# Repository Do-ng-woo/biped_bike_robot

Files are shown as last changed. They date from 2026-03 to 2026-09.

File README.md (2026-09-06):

# 🤖 Biped Bike Robot

> **biped_bike_robot_print_ver6** — SolidWorks에서 설계하고 실물 구동으로 검증 중인 **이족보행 ↔ 2구동 휠 + 볼캐스터 변환 로봇**  
> ROS 2 Jazzy + Gazebo Harmonic 환경

### ✨ 현재 URDF 반영 상태
- **최신 URDF**: `urdf/biped_bike_robot.urdf`
- **원본 익스포트**: `solidworks_export/urdf/biped_bike_robot_print_ver6.urdf`
- **구조**: 20 links, 19 joints = 17 actuated revolute joints + 2 continuous knee wheel joints
- **총 질량**: 약 **1.917 kg** (`base_link`에 메인 프레임, 배터리, 제어보드 질량 반영)
- **구동 모드**: 12자유도 이족보행, 팔 지지 기반 변신, 2륜 주행 모드

---

## 🎥 실물 구동 데모

### 1. 이족 보행 (Bipedal Walking)
Bipedal Walking Demo

### 2. 차륜형 변신 (Transform to Wheeled Mode)
Transform to Wheeled Mode

### 3. 이족 보행 모드 복귀 (Reverse Transform)
Reverse Transform

### 4. 바이크 모드 주행 (Wheeled Driving)
Wheeled Driving Demo

---

## 🎬 시뮬레이션 데모

### 1. 시뮬레이션 보행
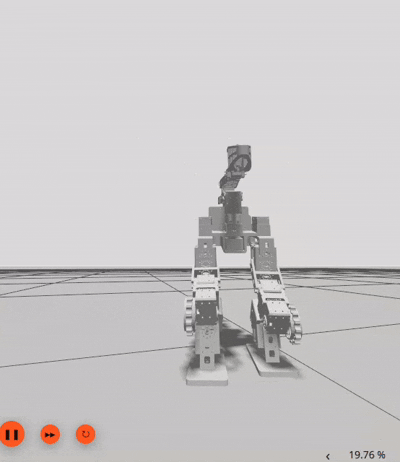
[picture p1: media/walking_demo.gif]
Simulation Walking Demo


### 2. 시뮬레이션 변신
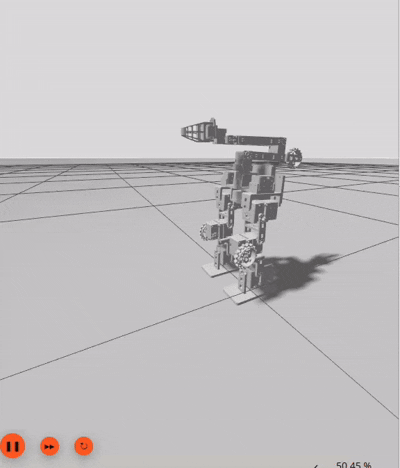
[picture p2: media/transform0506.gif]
Simulation Transform Demo


### 3. 시뮬레이션 역변신
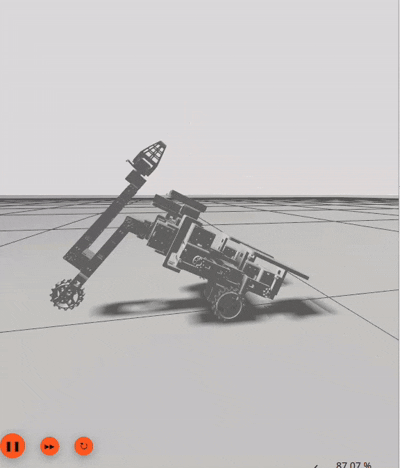
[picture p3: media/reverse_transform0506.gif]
Simulation Reverse Transform Demo


---

## 📐 관절 트리 다이어그램 (Joint Tree)

```
base_link (골반/허리 프레임)
├── [L] l_hip_yaw ──────── l_hip_yaw (좌측 고관절 요)
│   └── l_hip_roll ─────── l_hip_roll (좌측 고관절 롤)
│       └── l_hip_pitch ── l_hip_pitch (좌측 고관절 피치)
│           └── l_knee_pitch ── l_knee_pitch (좌측 무릎)
│               ├── l_ankle_pitch ── l_ankle_pitch (좌측 발목)
│               │   └── l_foot_roll ── l_foot_roll (좌측 발)
│               └── l_knee_pitch_wheel ── l_knee_pitch_wheel (좌측 무릎 휠) 🔄
│
├── [R] r_hip_yaw ──────── r_hip_yaw (우측 고관절 요)
│   └── r_hip_roll ─────── r_hip_roll (우측 고관절 롤)
│       └── r_hip_pitch ── r_hip_pitch (우측 고관절 피치)
│           └── r_knee_pitch ── r_knee_pitch (우측 무릎)
│               ├── r_ankle_pitch ── r_ankle_pitch (우측 발목)
│               │   └── r_foot_roll ── r_foot_roll (우측 발)
│               └── r_knee_pitch_wheel ── r_knee_pitch_wheel (우측 무릎 휠) 🔄
│
└── [U] arm_base_yaw ──── arm_base_yaw (팔 베이스 요)
    └── arm_shoulder_pitch ── arm_shoulder_pitch (어깨 피치)
        ├── arm_elbow_pitch ── arm_elbow_pitch (팔꿈치 피치)
        │   └── arm_wrist_pitch ── arm_wrist_pitch (손목 피치)
        │       └── arm_wrist_roll ── arm_wrist_roll (손목 롤)
```

> 🔄 = `continuous` 타입 (무한 회전 가능한 패시브 휠 관절)
> 현재 구조에서는 팔 끝 지지를 회전 휠 조인트가 아니라 볼캐스터 구조로 처리합니다.

---

## 📊 링크 목록 (20개)

| # | 링크 이름 | 위치 | 질량 (kg) | 설명 |
|---|---|---|---|---|
| 1 | `base_link` | 중심 | 0.626 | 골반/메인 프레임 (메인 기판 및 배터리 반영) |
| 2 | `l_hip_yaw` | 좌측 | 0.027 | 좌측 고관절 요 회전부 |
| 3 | `l_hip_roll` | 좌측 | 0.118 | 좌측 고관절 롤 링크 |
| 4 | `l_hip_pitch` | 좌측 | 0.014 | 좌측 고관절 피치 링크 |
| 5 | `l_knee_pitch` | 좌측 | 0.146 | 좌측 허벅지 (상부 다리) |
| 6 | `l_ankle_pitch` | 좌측 | 0.118 | 좌측 정강이 (하부 다리) |
| 7 | `l_foot_roll` | 좌측 | 0.075 | 좌측 발 |
| 8 | `l_knee_pitch_wheel` | 좌측 | 0.017 | 좌측 무릎 구동 휠 |
| 9 | `r_hip_yaw` | 우측 | 0.027 | 우측 고관절 요 회전부 |
| 10 | `r_hip_roll` | 우측 | 0.118 | 우측 고관절 롤 링크 |
| 11 | `r_hip_pitch` | 우측 | 0.014 | 우측 고관절 피치 링크 |
| 12 | `r_knee_pitch` | 우측 | 0.146 | 우측 허벅지 (상부 다리) |
| 13 | `r_ankle_pitch` | 우측 | 0.118 | 우측 정강이 (하부 다리) |
| 14 | `r_foot_roll` | 우측 | 0.075 | 우측 발 |
| 15 | `r_knee_pitch_wheel` | 우측 | 0.017 | 우측 무릎 구동 휠 |
| 16 | `arm_base_yaw` | 상체 | 0.053 | 팔 베이스 요 회전부 |
| 17 | `arm_shoulder_pitch` | 상체 | 0.105 | 상완 (어깨 피치) |
| 18 | `arm_elbow_pitch` | 상체 | 0.044 | 전완 (팔꿈치 피치) |
| 19 | `arm_wrist_pitch` | 상체 | 0.020 | 손목 피치 |
| 20 | `arm_wrist_roll` | 상체 | 0.039 | 손목 롤 / 엔드이펙터 |
> **총 질량**: 약 **1.917 kg** (URDF inertial mass 합산)

---

## 🔩 관절 목록 (19개)

### 좌측 다리 (Left Leg) — 6 액추에이터 + 1 패시브

| # | 관절 이름 | 타입 | 축 | 부모 → 자식 |
|---|---|---|-----|---|
| 1 | `l_hip_yaw` | revolute | Z(-) | base_link → l_hip_yaw |
| 2 | `l_hip_roll` | revolute | Z(-) | l_hip_yaw → l_hip_roll |
| 3 | `l_hip_pitch` | revolute | Z(+) | l_hip_roll → l_hip_pitch |
| 4 | `l_knee_pitch` | revolute | Z(-) | l_hip_pitch → l_knee_pitch |
| 5 | `l_ankle_pitch` | revolute | Z(-) | l_knee_pitch → l_ankle_pitch |
| 6 | `l_foot_roll` | revolute | Z(-) | l_ankle_pitch → l_foot_roll |
| 7 | `l_knee_pitch_wheel` | **continuous** | Z(-) | l_knee_pitch → l_knee_pitch_wheel |

### 우측 다리 (Right Leg) — 6 액추에이터 + 1 패시브

| # | 관절 이름 | 타입 | 축 | 부모 → 자식 |
|---|---|---|-----|---|
| 8 | `r_hip_yaw` | revolute | Z(-) | base_link → r_hip_yaw |
| 9 | `r_hip_roll` | revolute | Z(-) | r_hip_yaw → r_hip_roll |
| 10 | `r_hip_pitch` | revolute | Z(-) | r_hip_roll → r_hip_pitch |
| 11 | `r_knee_pitch` | revolute | Z(-) | r_hip_pitch → r_knee_pitch |
| 12 | `r_ankle_pitch` | revolute | Z(-) | r_knee_pitch → r_ankle_pitch |
| 13 | `r_foot_roll` | revolute | Z(-) | r_ankle_pitch → r_foot_roll |
| 14 | `r_knee_pitch_wheel` | **continuous** | Z(+) | r_knee_pitch → r_knee_pitch_wheel |

### 상체 (Upper Body) — 5 액추에이터

| # | 관절 이름 | 타입 | 축 | 부모 → 자식 |
|---|---|---|-----|---|
| 15 | `arm_base_yaw` | revolute | Z(-) | base_link → arm_base_yaw |
| 16 | `arm_shoulder_pitch` | revolute | Z(+) | arm_base_yaw → arm_shoulder_pitch |
| 17 | `arm_elbow_pitch` | revolute | Z(+) | arm_shoulder_pitch → arm_elbow_pitch |
| 18 | `arm_wrist_pitch` | revolute | Z(-) | arm_elbow_pitch → arm_wrist_pitch |
| 19 | `arm_wrist_roll` | revolute | Z(-) | arm_wrist_pitch → arm_wrist_roll |

---

## 🦿 설계 특징

### 1. 좌우 대칭 이족 구조
- 각 다리: **6 DOF** (Hip Yaw → Hip Roll → Hip Pitch → Knee Pitch → Ankle Pitch → Foot Roll)
- 좌우 다리는 `base_link`에서 Y축 방향으로 오프셋 (좌: y=-0.01425, 우: y=-0.13925)
- 고관절 롤(Roll)은 `rpy="0 -π/2 0"`로 90° 회전하여 측면 운동축을 구현

### 2. 차륜 모드를 위한 휠과 볼캐스터
- `l_knee_pitch_wheel_jnt`, `r_knee_pitch_wheel_jnt` — 2개의 **continuous** 구동 휠 관절
- 팔 끝 지지는 `arm_wheel_pitch_` 조인트 없이 볼캐스터 구조로 처리

### 3. 단일 팔 지지 구조
- `arm_base_yaw` → `arm_shoulder_pitch` → `arm_elbow_pitch` → `arm_wrist_pitch` → `arm_wrist_roll`
- `arm_wrist_roll`이 자전거 핸들을 잡는 최종 엔드이펙터

### 4. 서보 모터 기반 소형 로봇
- 총 질량 약 **1.917 kg**
- 모든 메시가 STL 형식 (SolidWorks 직접 내보내기)
- URDF에는 Gazebo friction/contact 및 `ros2_control` 인터페이스가 포함되어 있습니다.

---

## 📁 패키지 구조

```
biped_bike_robot/
├── CMakeLists.txt
├── package.xml
├── RL_walking/                 ← 독립형 NumPy RL 보행 + OpenCR 브리지
├── manipulator/                ← 리더/팔로워/카메라/지도학습 웹 스택
├── README.md                    ← 이 문서
├── config/
│   ├── controllers.yaml         ← ros2_control 컨트롤러 설정
│   └── dynamixel_hardware.yaml  ← 실물 Dynamixel ID/방향/제한 설정
├── launch/
│   ├── display.launch.py        ← RViz 모델 표시
│   ├── gazebo.launch.py         ← Gazebo 시뮬레이션 런치
│   └── hardware_display.launch.py ← 실물 브릿지 + RViz/robot_state_publisher
├── media/
│   ├── walking.gif              ← 실물 보행 데모
│   ├── transform.gif            ← 실물 변신 데모
│   ├── revert_transform.gif     ← 실물 역변신 데모
│   ├── drive.gif                ← 실물 주행 데모
│   ├── walking_demo.gif         ← 시뮬레이션 보행 데모
│   ├── transform0506.gif        ← 시뮬레이션 변신 데모
│   └── reverse_transform0506.gif ← 시뮬레이션 역변신 데모
├── meshes/                      ← 메시 파일 (20개 STL)
│   ├── base_link.STL
│   ├── l_hip_yaw.STL
│   ├── l_hip_roll.STL
│   ├── l_hip_pitch.STL
│   ├── l_knee_pitch.STL
│   ├── l_ankle_pitch.STL
│   ├── l_foot_roll.STL
│   ├── l_knee_pitch_wheel.STL
│   ├── r_hip_yaw.STL
│   ├── r_hip_roll.STL
│   ├── r_hip_pitch.STL
│   ├── r_knee_pitch.STL
│   ├── r_ankle_pitch.STL
│   ├── r_foot_roll.STL
│   ├── r_knee_pitch_wheel.STL
│   ├── arm_base_yaw.STL
│   ├── arm_shoulder_pitch.STL
│   ├── arm_elbow_pitch.STL
│   ├── arm_wrist_pitch.STL
│   └── arm_wrist_roll.STL
├── urdf/
│   └── biped_bike_robot.urdf    ← 최신 보정 URDF (print ver6 기반)
├── scripts/
│   ├── ik_walker.py             ← IK 기반 보행 엔진
│   ├── transform_bike.py        ← 바이크 모드 변신 시퀀스
│   ├── revert_bike.py           ← 이족보행 모드 복구 시퀀스
│   ├── bike_teleop.py           ← 키보드(WASD) 주행 컨트롤러
│   ├── dxl_joint_state_bridge.py ← 실물 Dynamixel 브릿지
│   ├── imu_base_tf.py           ← 실물 자세 TF 보정
│   ├── web_control.py           ← 실물 테스트용 웹 컨트롤 패널
│   ├── ready_posture.py         ← 기본 준비 자세 초기화
│   └── patch_urdf.py            ← SolidWorks→ROS 2 자동 보정 도구
└── solidworks_export/             ← SolidWorks 원본 (수정 금지)
    ├── README.md
    ├── urdf/biped_bike_robot_print_ver6.urdf
    └── meshes/
```

## 🌐 통합 웹 제어

ROS 2 Jazzy 환경에서 소스 패키지의 통합 웹 패널을 실행합니다.

```bash
python3 scripts/web_control.py
```

다른 PC에서는 `http://로봇_IP:8080`으로 접속합니다. 첫 화면의 **RL
Walking**은 패키지 내부 `RL_walking/models/model_90000.npz`를 사용하며,
W/↑ 전진, A/←·D/→ 횡이동, Q/E 회전, Space 정지로 동작합니다. 키를
놓으면 dead-man 타임아웃으로 정지 명령이 전송됩니다.

상단 **Manipulator** 링크는 별도 페이지를 열고, OpenCR 하체/팔로워,
OpenRB 리더, USB 카메라와 매니퓰레이터 UI를 한 번에 시작합니다.
RL 보행, 기존 하드웨어 브리지, 매니퓰레이터 스택은 같은 OpenCR 포트를
사용하므로 웹 서버가 세 모드의 동시 실행을 차단합니다.

---

## 🔗 관절 연쇄 다이어그램 (Kinematic Chain)

```mermaid
graph TD
    B["base_link<br/>골반 프레임<br/>626g"]

    B -->|l_hip_yaw| LHY["l_hip_yaw<br/>27g"]
    LHY -->|l_hip_roll| LHR["l_hip_roll<br/>118g"]
    LHR -->|l_hip_pitch| LHP["l_hip_pitch<br/>14g"]
    LHP -->|l_knee_pitch| LK["l_knee_pitch<br/>146g"]
    LK -->|l_ankle_pitch| LA["l_ankle_pitch<br/>118g"]
    LA -->|l_foot_roll| LF["l_foot_roll<br/>75g"]
    LK -.->|wheel| LKW["l_knee_pitch_wheel 🔄<br/>17g"]

    B -->|r_hip_yaw| RHY["r_hip_yaw<br/>27g"]
    RHY -->|r_hip_roll| RHR["r_hip_roll<br/>118g"]
    RHR -->|r_hip_pitch| RHP["r_hip_pitch<br/>14g"]
    RHP -->|r_knee_pitch| RK["r_knee_pitch<br/>146g"]
    RK -->|r_ankle_pitch| RA["r_ankle_pitch<br/>118g"]
    RA -->|r_foot_roll| RF["r_foot_roll<br/>75g"]
    RK -.->|wheel| RKW["r_knee_pitch_wheel 🔄<br/>17g"]

    B -->|arm_base_yaw| ABY["arm_base_yaw<br/>53g"]
    ABY -->|shoulder_pitch| ASP["arm_shoulder_pitch<br/>105g"]
    ASP -->|elbow_pitch| AEP["arm_elbow_pitch<br/>44g"]
    AEP -->|wrist_pitch| AWP["arm_wrist_pitch<br/>20g"]
    AWP -->|wrist_roll| AWR["arm_wrist_roll<br/>39g"]

    style B fill:#4a90d9,color:#fff
    style LF fill:#2ecc71,color:#fff
    style RF fill:#2ecc71,color:#fff
    style AWR fill:#e74c3c,color:#fff
    style LKW fill:#f39c12,color:#fff
    style RKW fill:#f39c12,color:#fff
```

---

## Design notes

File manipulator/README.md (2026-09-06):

# Biped Bike Manipulator (native ROS 2)

이 폴더는 Docker 없이 ROS 2 Jazzy 호스트에서 다음 기능을 한 번에 실행한다.

- 기존 12축 하체를 변신 시퀀스의 `DEEP_SQUAT_ARMS_UP` 하체 각도로 이동하고 지속 고정
- OpenRB에 연결된 OMX-L 리더 6축(ID 21~26)을 실제 팔로워 6축(ID 15~20)으로 텔레오퍼레이션
- U20CAM 영상, 실제 팔 관절각, 리더 목표각을 에피소드 단위로 기록
- 로컬 GPU에서 영상 기반 지도학습(behavior cloning)
- 학습 모델을 불러와 실제 팔에 추론 명령 전송
- 브라우저에서 상태·카메라·기록·학습·추론 제어

다른 `biped_bike_robot` 파일은 수정하지 않는다. 하체는 외부 PD 루프를 사용하지 않는다. 활성 모드에서는 하나의 command arbiter가 매 주기 하체 고정 12축과 팔/그리퍼 목표 6축을 합친 18축 trajectory를 발행하고, Dynamixel 내부 position PID가 이를 추종한다. 휠 명령은 모든 모드에서 계속 0으로 보낸다.

## 안전 및 현재 범위

팔로워의 기존 5축 뒤에 `arm_gripper_jnt`를 추가해 OpenCR ID 20과 연결한다. 리더 `gripper_joint_1`(OpenRB ID 26)의 시작 위치를 팔로워 ID 20의 시작 위치에 자동 정렬한 뒤 상대 각도를 추종한다. 실행 시 원본 하드웨어 YAML을 수정하지 않고 `data/runtime/dynamixel_hardware_with_gripper.yaml`을 생성한다. ID 20은 다른 팔 관절과 동일한 일반 Position Control Mode(Operating Mode 3)를 사용한다. Wizard에서 측정한 팔로워 기구 끝점은 닫힘 181.14도(2061 tick), 열림 108.63도(1236 tick)다. 닫힘은 기구 끝점에서 약 0.5도 여유를 둔 2055 tick, 열림은 1.22 rad 범위로 사용한다. 기록에서 열림 값이 증가하는 리더 ID 26은 `+1`, 열릴 때 tick이 감소하는 팔로워 ID 20의 하드웨어 변환은 `-1`로 두어 서로 반대인 물리 회전 방향을 맞춘다. 리더의 더 큰 gripper 회전 범위에는 0.72 배율을 적용해 팔로워 개폐율로 환산하므로 중간 영역이 양 끝값에 포화되지 않는다. ID 20 PWM limit은 다른 관절과 같은 885다.

실시간 텔레옵에서는 기존 브리지의 18개 개별 위치 읽기를 사용하지 않는다. 이 폴더의 `dxl_joint_state_bridge_streaming.py`가 원본 브리지를 읽어 확장하고, 20개 모터 상태를 ID 1~7, 8~14, 15~20의 세 GroupSyncRead로 나눠 20 Hz 수집한다. 한 하체 그룹의 패킷이 빠져도 팔과 그리퍼 피드백은 독립적으로 유지된다. 30 Hz로 들어오는 단일 목표점은 매번 보간을 재시작하지 않고 즉시 GroupSyncWrite하며 1 tick 변화부터 반영한다. Ready/Kneeling 같은 다점 궤적만 기존 시간 보간을 유지한다. 원본 `scripts/dxl_joint_state_bridge.py`는 수정하지 않는다.

처음에는 로봇을 공중에 띄우거나 비상 정지가 가능한 상태에서 낮은 속도로 확인한다. `config/system.yaml`의 `arm.direction`, `arm.offset`, 관절 한계가 실제 장착 방향과 맞는지 축별로 확인해야 한다. 기존 주행/변신 제어 프로그램과 이 프로그램을 동시에 실행하면 같은 모터 명령 토픽을 두 노드가 사용할 수 있으므로 동시에 실행하지 않는다.

## 1. 환경 준비

ROS와 기존 두 워크스페이스를 먼저 불러온다.

```bash
source /opt/ros/jazzy/setup.bash
source /home/dongwoo/install/setup.bash
source /home/dongwoo/biped_bike_ws/install/setup.bash
cd /home/dongwoo/biped_bike_ws/src/biped_bike_robot/manipulator
```

학습 환경은 최초 한 번만 설치한다. PyTorch와 OpenCV가 이 폴더의 `.venv-training`에 설치되고 호스트 ROS 패키지는 읽기 전용으로 공유되며, 다른 Python 환경을 바꾸지 않는다.

```bash
./setup_native.sh
```

장치까지 점검한다.

```bash
./validate_native.py --hardware --leader --camera --training
```

`/dev/opencr`가 없다면 기존 biped 하드웨어 설정에서 사용하는 udev 별칭을 먼저 준비한다. 카메라 번호가 달라졌다면 안정적인 `/dev/v4l/by-id/...-video-index0` 경로로 `config/system.yaml`의 `camera.device`를 바꾸는 것이 좋다.

## 2. 실행

현재 Docker 버전이 카메라나 OpenRB를 잡고 있다면 먼저 해당 컨테이너를 중지한다. 그 뒤:

```bash
./run_native.sh --hardware --leader --camera --ready-on-start
```

브라우저에서 `http://localhost:8000`을 연다. 같은 네트워크의 다른 PC에서는 `http://노트북_IP:8000`으로 접속한다.

하드웨어 없이 UI와 ROS 노드만 확인하려면:

```bash
./run_native.sh
```

`--ready-on-start`를 준 경우에만 OpenCR 브리지가 초기화된 뒤 ID 20 gripper를 포함한 완전한 18축 `/joint_states`를 먼저 기다린다. 그 실측 자세에서 기존 `scripts/bike_transform_sequence.py`의 `HARDWARE_READY`와 gripper 중립값 0 rad까지, MJLab `run_ros_bridge.py`와 같은 cubic smoothstep(`a=t²(3-2t)`) 프로파일을 50 Hz/151개 궤적점으로 만들어 3초 동안 이동한다. 따라서 3초를 기다렸다가 목표로 튀는 방식이 아니며 시작과 끝 속도도 완만하다. 브리지 자체의 즉시 startup posture는 항상 끈다. 실제 로봇을 지지하고 주변을 비운 상태에서 사용한다. 옵션을 생략하면 시작 시 자동 자세 이동은 하지 않는다. 초기 고정 모드에서는 OpenCR IMU를 사용하지 않는다.

하체는 ROS overlay에서 발견되는 오래된 설치본을 사용하지 않고 `config/system.yaml`에 지정된 현재 biped 소스의 `dxl_joint_state_bridge.py`를 직접 실행한다. 원본 `dynamixel_hardware.yaml`에 이 모듈의 ID 20 설정만 합친 런타임 YAML을 사용한다. 리더도 크래시 이력이 있는 `omx_l_leader_ai.launch.py`/`controller_manager` 대신 이 모듈의 `leader_openrb_reader.py`가 OpenRB ID 21~26의 Present Position만 읽는다. 이 리더 노드는 위치 및 토크 명령을 전송하지 않는다.

## 3. 텔레오퍼레이션

웹에서 다음 두 버튼을 순서대로 누른다.

1. **1. Kneeling Stable**: 휠 속도를 0으로 만들고 전체 18축을 기존 `DEEP_SQUAT_ARMS_UP`과 gripper 중립 자세로 4초 동안 smoothstep 이동한다. 실제 하체 관절이 목표 오차 0.12 rad 안에서 0.5초 유지돼야 상태가 `STABLE`이 된다.
2. **2. Manipulating Teleop**: `STABLE` 상태에서만 활성화된다. 리더와 팔로워의 현재 위치를 6축 모두 자동 정렬한 뒤 팔과 gripper 명령을 허용한다.

Record와 Inference도 동일하게 먼저 `STABLE` 확인이 필요하다. 안정화 전 직접 요청해도 웹 API와 ROS 상태 머신 양쪽에서 거부한다.

전환이 15초 안에 완료되지 않으면 `FAULT`가 되고 팔 명령은 차단된다. 활성화 후에도 하체 오차와 joint-state 수신을 계속 감시하며, 허용 오차가 0.3초 이상 지속되거나 상태 수신이 끊기면 `FAULT`로 전환한다. **Arm Stop / Idle**은 새 팔 명령을 끊지만 하체는 마지막 고정 목표를 유지한다.

자세 숫자는 이 폴더에 복사해 두지 않고 기존 `scripts/bike_transform_sequence.py`에서 매 실행 시 직접 읽는다.

| 관절 | Ready | Manipulation kneeling |
|---|---:|---:|
| 왼 hip pitch | 0° | -44.48° |
| 오른 hip pitch | 0° | +44.48° |
| 양 knee pitch | -17.19° | -120° |
| 양 ankle pitch | +18.59° | +85° |
| arm shoulder pitch | -70° | -70° |
| arm elbow pitch | 0° | +20° |

무릎 전환 timeout 시 웹 상태의 `lower_error_rad`와 `largest errors`에 목표에서 가장 멀리 남은 관절이 표시된다. `Skipped ... trajectory joints over their absolute command limits`가 나오면 현재 관절 zero/center 설정을 먼저 확인한다. 실행 로그의 Dynamixel config 경로는 이 모듈 아래 `manipulator/data/runtime/dynamixel_hardware_with_gripper.yaml`이어야 한다.

## 4. 데이터 기록

웹의 Dataset recording 항목을 채우고 **Start**를 누른다. UI가 먼저 고정 무릎 자세 완료를 기다린 뒤 기록을 시작한다.

- `Warmup`: 준비 시간
- `Episode sec`: 한 에피소드 기록 시간
- `Reset timeout sec`: 팔을 기존 `DEEP_SQUAT_ARMS_UP`의 팔 자세로 복귀시키는 제한 시간
- `Stop`: 현재 에피소드를 저장하고 일시 정지
- `Retry`: 현재/직전 에피소드를 버리고 다시 기록
- `Next`: 현재 에피소드를 저장하고 다음 에피소드로 이동
- `Finish`: 남은 유효 샘플을 저장하고 데이터셋 확정

에피소드 사이에는 팔로워를 설정된 reset 자세로 이동시키고 실제 관절 오차가 허용 범위에서 0.5초 유지되는지 확인한다. 그 뒤 리더 기준을 현재 팔로워 자세에 다시 정렬하고 다음 warmup을 시작한다.

데이터는 이 폴더 아래 `data/datasets/<user>/<name_timestamp>/`에만 저장한다. 각 에피소드에는 JPEG 프레임, `camera.mp4`, `samples.npz`, `episode.json`이 생긴다. `samples.npz`에는 카메라 시간, 실제 팔 관절 시간·각도(`observation_state`), 리더 목표 시간·각도(`action`)가 저장된다. 카메라를 기준으로 가장 가까운 관절/명령 샘플을 선택하고 기본 50 ms를 초과한 조합은 기록하지 않는다.

## 5. 학습과 실행

**Finish** 후 Training의 Refresh를 누르고 데이터셋을 선택한 뒤 **Start Training**을 누른다. 기본 모델은 카메라 영상과 현재 팔 관절각에서 다음 팔 목표각을 예측하는 작은 supervised behavior-cloning 모델이다. 결과는 `data/models/<output>/best.pt`에 저장되고 로그는 같은 폴더의 `console.log`와 `training.jsonl`에 남는다.

학습/검증 데이터는 프레임이 아니라 에피소드 단위로 분리하므로 같은 시연의 인접 프레임이 양쪽에 섞이지 않는다. 정규화 통계도 학습 에피소드로만 계산한다.

학습 후 Inference model에서 `best.pt`를 선택해 **Load Model**, 이어서 **Manipulating Inference**를 누른다. 모델의 6축 이름·순서, 입출력 차원, 정규화 값을 실제 로봇과 비교하고 추론 노드의 `LOADED` 응답을 받은 경우에만 INFERENCE 진입을 허용한다. 기존 5축 데이터셋과 모델은 새 6축 계약과 호환되지 않으므로 새로 기록·학습해야 한다. 실제 로봇 적용 전에는 낮은 `arm.max_velocity_rad_s`로 시작하고 반드시 사람이 비상 정지할 수 있어야 한다.

이 초기 모델은 ACT나 diffusion policy가 아닌 검증용 1-step BC 기준선이다. 수집·안전·모드 전환 인터페이스를 그대로 유지하면서 나중에 `learning/model.py`와 `nodes/policy_inference.py`만 ACT 등으로 교체할 수 있다.

## ROS 인터페이스

| 용도 | 토픽 |
|---|---|
| 실제 전체 관절 상태 | `/joint_states` |
| 기존 하드웨어 trajectory | `/joint_trajectory_controller/joint_trajectory` |
| 리더 입력 | `/leader/joint_trajectory` |
| 매핑된 텔레옵 목표 | `/manipulator/teleop_target` |
| 추론 목표 | `/manipulator/inference_target` |
| 모드 요청/상태 | `/manipulator/mode/request`, `/manipulator/mode/state` |
| 기록 요청/상태 | `/manipulator/record/command`, `/manipulator/record/state` |
| 모델 요청/로드 상태 | `/manipulator/inference/model`, `/manipulator/inference/model_state` |
| 카메라 | `/camera1/image_raw/compressed` |

모든 배선, 자세, 한계, 속도, 저장 위치는 `config/system.yaml`에서 관리한다.

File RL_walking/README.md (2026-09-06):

# RL Walking runtime

This directory is a Raspberry Pi runtime copy of the verified 50 Hz walking
pipeline. It does not import files from `mjlab` and uses the exported NumPy
policy at `models/model_90000.npz`; PyTorch is not required on the robot.

The web panel starts `run_rl_stack.py`, which owns the OpenCR serial port,
starts the policy stopped, and exposes a loopback dead-man command server on
port 8081. Never run this stack together with `hardware_display.launch.py` or
the manipulator hardware stack because only one process may own OpenCR.

Run the main package web panel from a ROS 2 Jazzy shell:

```bash
python3 scripts/web_control.py
```

Open `http://ROBOT_IP:8080`, press **Start RL Walking**, wait for READY and IMU
calibration, then hold an arrow/WASD/Q/E control. Releasing the key or losing
the browser heartbeat sends STOP. **Stop RL Walking** returns to READY before
disabling torque and releasing OpenCR.

Required Python packages are `numpy`, `PyYAML`, `dynamixel-sdk`, and the ROS 2
Jazzy Python packages used by `rclpy`.

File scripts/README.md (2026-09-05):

# Biped Bike Robot Scripts

이 폴더는 로봇의 자세 전환, 보행 궤적 생성, 바이크 모드 주행, URDF 보정, 실기 브릿지를 담당하는 실행 스크립트를 담고 있습니다.

런치 파일 실행법과 하드웨어 파라미터는 `launch/README.md`를 봅니다.

## 보행

### `ik_walker.py`

12자유도 다리 보행 엔진입니다. 사인파 기반 발 궤적과 해석적 IK로 계산한 17개 관절 목표를 `JointTrajectory`로 만들어 `/joint_trajectory_controller/joint_trajectory`에 publish합니다.

실행 예:

```bash
ros2 run biped_bike_robot ik_walker.py
```

워커는 현재 실물 자세에서 보행 시작 자세까지 기본 3초 동안 부드럽게
이동한 뒤 첫 스텝을 시작합니다. 이 시간은 보행 슬로모션 배율과 별개입니다.

```bash
ros2 run biped_bike_robot ik_walker.py --ros-args \
  -p startup_duration_sec:=3.0
```

### 실기에서 잘 걷는 검증 보정값

아래 조합은 실제 하드웨어에서 보행이 잘 되는 것으로 확인한 보정값입니다.

```bash
ros2 run biped_bike_robot ik_walker.py --ros-args \
  -p num_cycles:=1 \
  -p support_hip_roll_lift_deg:=20.0 \
  -p support_ankle_roll_lift_deg:=10.0 \
  -p support_ankle_roll_lift_sign:=1.0 \
  -p pelvis_pitch_forward_lift_deg:=30.0 \
  -p pelvis_pitch_forward_lift_sign:=1.0 \
  -p trajectory_time_scale:=4.0
```

중요 포인트:

- `num_cycles`: 한 사이클이 좌/우 2보입니다. 위 검증 명령은 `1`이라 총 2보만 테스트합니다.
- `support_hip_roll_lift_deg`: 한 발 지지 때 힙 롤로 좌우 처짐을 보정합니다.
- `support_ankle_roll_lift_deg`: 지지발 발목/발 롤로 바닥 반력을 보정합니다.
- `pelvis_pitch_forward_lift_deg`: 한발만 땅에 닿고 반대발을 뻗는 동안, 땅에 닿아 있는 지지발 hip pitch에만 들어가는 동적 전방 보정입니다. 위 검증값은 `30도`입니다.
- `trajectory_time_scale`: 같은 궤적을 느리게 재생합니다. 위 조합은 4배 느린 재생입니다.
- `startup_duration_sec`: 현재 자세에서 워커 시작 자세로 이동하는 시간입니다. 기본값은 3초이며 `trajectory_time_scale`의 영향을 받지 않습니다.
- 보행 끝에는 별도의 복귀 스텝을 만들지 않습니다. 요청한 사이클 수만큼 걷고 마지막 자세를 유지하므로, 발 방향이 바뀌는 어색한 마무리 동작을 피할 수 있습니다.

자주 쓰는 파라미터:

```bash
ros2 run biped_bike_robot ik_walker.py --ros-args \
  -p z_move_amplitude:=0.070 \
  -p y_swap_amplitude:=-0.047 \
  -p x_move_amplitude:=-0.025 \
  -p x_swap_forward_bias:=-0.006 \
  -p x_swap_time_advance_ratio:=0.08 \
  -p init_x_offset:=-0.030 \
  -p init_z_offset:=0.050 \
  -p hip_pitch_offset_deg:=10.0 \
  -p period_time:=3.0 \
  -p dsp_ratio:=0.50 \
  -p foot_lift_delay_ratio:=0.20 \
  -p pelvis_offset_deg:=0.0 \
  -p support_hip_roll_lift_deg:=10.0 \
  -p support_ankle_roll_lift_deg:=0.0 \
  -p swing_foot_pitch_lift_deg:=0.0 \
  -p swing_ankle_pitch_lift_deg:=0.0 \
  -p pelvis_pitch_forward_lift_deg:=5.0 \
  -p arm_shoulder_pitch_deg:=-70.0 \
  -p trajectory_time_scale:=1.5
```

주요 파라미터 의미:

- `x_move_amplitude`: 전후 보폭입니다. 현재 로봇 기준 전진은 음수입니다.
- `step_fb_ratio`: 보폭에 비례해 상체/골반 기준점을 앞뒤로 흔드는 비율입니다. 키우면 앞뒤 스윙 전체가 커집니다.
- `x_swap_forward_bias`: 앞뒤 스윙의 중심을 전진 방향으로 옮기는 값입니다. 현재 로봇 기준 전진은 음수이므로, `-0.006`은 전체 스윙을 약 6mm 앞으로 보냅니다.
- `x_swap_time_advance_ratio`: 앞뒤 무게중심 이동 타이밍을 보행 주기 대비 얼마나 앞당길지 정합니다. `0.08`은 한 주기의 8%만큼 먼저 움직입니다.
- `init_x_offset`: 준비 자세부터 적용되는 골반/상체 전후 기준점입니다. 현재 기본값 `-0.030`은 약 3cm 전방입니다.
- `init_z_offset`: 준비 자세부터 적용되는 몸 높이 보정입니다. 값을 키우면 무릎/발목 pitch가 더 접히고 무게중심이 낮아집니다. ver5 긴 정강이 기준 기본값은 `0.050`입니다.
- `hip_pitch_offset_deg`: 기본 hip pitch 전방 기울임입니다. 앞으로 넘어지면 값을 줄여 테스트합니다.
- `z_move_amplitude`: 발을 들어 올리는 높이입니다. 현재 기본값 `0.070`은 약 7cm입니다.
- `y_swap_amplitude`: 상체/무게중심을 좌우로 이동시키는 양입니다. 현재 기본값 `-0.047`은 중심 기준 약 4.7cm, 왕복 약 9.4cm입니다.
- `period_time`: 보행 엔진 내부 한 주기 시간입니다. 발 궤적의 phase 계산 자체가 바뀌므로 단순 슬로우모션에는 `trajectory_time_scale`을 사용합니다.
- `foot_lift_delay_ratio`: 한 발 지지 구간 시작 후, 이 비율만큼 무게중심을 먼저 옮긴 뒤 발을 듭니다. 골반은 지지발 쪽에 머문 상태로 발을 들어 올리고 내려놓으며, 발이 착지한 뒤에 다음 방향으로 이동합니다. 발을 늦게 든 만큼 착지 완료 시점도 뒤로 밀어 보행 주기를 늘리므로, 내려놓는 궤적을 압축하지 않습니다.
- `trajectory_time_scale`: 생성된 같은 보행 궤적의 timestamp만 늘리거나 줄입니다. `2.0`이면 2배 느린 슬로우모션입니다.
- `x_move_start_scale`: 출발 첫 보행의 보폭 비율입니다. 현재 기본값은 `1.0`이라 처음부터 100% 보폭입니다.
- `x_move_ramp_per_cycle`: 보행 주기마다 보폭을 늘리는 비율입니다. 현재 기본값은 `0.0`이라 ramp 없이 고정 보폭입니다.
- `dsp_ratio`: 양발 지지 구간 비율입니다. 크게 할수록 발을 들기 전에 무게 이동 시간이 길어집니다.
- `pelvis_offset_deg`: 골반 롤 오프셋입니다. 상체 수평 우선 테스트에서는 `0.0`을 권장합니다.
- `support_hip_roll_lift_deg`: 실기 보정값입니다. 한쪽 발이 들릴 때 지지발 hip roll에 점진적으로 더하는 최대 각도입니다.
- `support_hip_roll_lift_sign`: 지지발 hip roll 보정 방향입니다. 보정 후 더 기울어지면 `-1.0`으로 바꿔 테스트합니다.
- `support_ankle_roll_lift_deg`: 실기 보정값입니다. 한쪽 발이 들릴 때 지지발 ankle/foot roll에 점진적으로 더하는 최대 각도입니다.
- `support_ankle_roll_lift_sign`: 지지발 ankle/foot roll 보정 방향입니다. 보정 후 더 기울어지면 `-1.0`으로 바꿔 테스트합니다.
- `swing_foot_pitch_lift_deg`: 실기 보정값입니다. 진행발이 들릴 때 스윙발 pitch에 점진적으로 더하는 최대 각도입니다. 뒤꿈치가 끌리면 부호를 바꿔가며 테스트합니다.
- `swing_foot_pitch_lift_sign`: 스윙발 pitch 보정 방향입니다.
- `swing_ankle_pitch_lift_deg`: 실기 보정값입니다. 진행발이 들릴 때 스윙발 ankle pitch 관절에 직접 더하는 최대 각도입니다. 앞꿈치가 과하게 들리고 뒤꿈치가 끌릴 때 5도 정도부터 테스트합니다.
- `swing_ankle_pitch_lift_sign`: 스윙발 ankle pitch 직접 보정 방향입니다. 뒤꿈치가 더 끌리면 `-1.0`으로 바꿔 테스트합니다.
- `pelvis_pitch_forward_lift_deg`: 실기 보정값입니다. 한쪽 발이 나가는 동안에만 지지발 hip pitch에 적용되는 보정 최대 각도입니다.
- `pelvis_pitch_forward_lift_sign`: 골반 pitch 보정 방향입니다. 보정 후 골반이 더 뒤로 누우면 `-1.0`으로 바꿔 테스트합니다.
- `arm_shoulder_pitch_deg`: 보행 중 유지할 어깨 pitch 각도입니다. 실물 기본값은 뒤쪽으로 접은 `-70.0`이며, 팔꿈치 pitch는 0도로 유지합니다.
- `num_cycles`: 생성할 보행 주기 수입니다. 한 주기는 좌/우 2보이므로 `1`이면 2보, `5`이면 10보입니다.

## 준비 자세와 변신

### `ready_posture.py`

보행 전 사용할 기본 준비 자세를 보냅니다. 무릎을 약간 굽히고, 뒤쪽이 무거운 실물 기준으로 hip pitch를 앞으로 5도 더 기울이며, 어깨 pitch를 뒤쪽으로 70도 접어 로봇을 안정적인 시작 자세로 정렬할 때 사용합니다. 팔꿈치 pitch는 0도로 유지합니다.

```bash
ros2 run biped_bike_robot ready_posture.py
```

현재 자세에서 레디 자세까지 기본 3초 동안 선형 보간합니다. 시간을 바꾸려면:

```bash
ros2 run biped_bike_robot ready_posture.py --ros-args \
  -p move_duration_sec:=4.0
```

실물 기본 보정값:

- `forward_lean_deg`: 기본값 `5.0`. 좌우 hip pitch에 추가하는 전방 기울임입니다.
- `arm_shoulder_pitch_deg`: 기본값 `-70.0`. ready/walker 중 어깨 pitch를 뒤쪽으로 접어 유지하는 각도입니다. 팔꿈치 pitch는 0도로 유지합니다.

### `transform_bike.py`

이족보행 모드에서 바이크 모드로 변형하는 시퀀스를 보냅니다.
안정적으로 일어나는 `revert_bike.py`의 경로를 역순으로 사용하며, 몸통을
접고 펴는 동안 어깨 관절을 기구 한계인 `-25도`(`-0.436332 rad`)로
유지해 전방 낙하를 막습니다. 이 값보다 뒤로 가는 명령은 실물 브릿지와
Gazebo URDF에서 모두 차단됩니다.
손목은 pitch를 아래로 접기 전에 `arm_wrist_roll_jnt`를 먼저 `180도` 돌린
뒤, 그 상태를 유지한 채 claw pitch를 접습니다.
변신 중 팔꿈치 pitch가 열려 있는 지지/완성 자세는 기존 `10도` 대신
`20도`를 사용하고, 완전한 바이크 자세의 어깨 pitch는 뒤쪽 `-70도` 자세를
유지합니다.
완전한 바이크 자세에서는 hip yaw도 안쪽으로 모아 왼쪽 `+5도`, 오른쪽
`-5도`를 적용합니다. 리버트는 이 자세에서 시작한 뒤 다음 지지 waypoint로
넘어가며 hip yaw가 다시 0도로 풀립니다.

```bash
ros2 run biped_bike_robot transform_bike.py
```

각 단계의 기본 시간은 3초입니다. Gazebo에서 더 느리게 확인하려면:

```bash
ros2 run biped_bike_robot transform_bike.py --ros-args \
  -p stage_duration_sec:=5.0
```

### `revert_bike.py`

바이크 모드에서 다시 이족보행 모드로 돌아오는 시퀀스를 보냅니다.
변신 코드와 공용 자세 정의를 사용하며, 리버트에는 기립 안정화를 위한 중간
waypoint가 포함됩니다. 반복되는 어깨 값은 별도 제약이 아니라 지지 자세를 계속
유지하는 위치 명령입니다.
리버트 초반에는 접힌 claw 상태에서 `arm_wrist_roll_jnt`의 `180도` 자세를
유지한 채 wrist pitch를 먼저 펴고, 이후 arm yaw 복귀 단계에서 wrist roll도
원위치로 돌아옵니다.

기립 구간은 8.0 이후에 별도 waypoint로 나뉩니다. 8.0에서는 arm yaw만
복귀하고 deep squat 자세를 유지합니다. 8.5에서는 무릎/발목은 그대로 둔 채
hip pitch만 READY 방향으로 약 `10도` 먼저 복귀해 뒤쪽 체중을 만듭니다.
이후 9.0, 9.6, 10.2에서 무릎/발목은 각각 `30%`, `65%`, `85%` 펴지고,
hip pitch는 deep squat 기준 누적 `25도`, `38도`, `43도` 복귀합니다.
마지막 10.7에서 `HARDWARE_READY` 자세로 정착합니다.

```bash
ros2 run biped_bike_robot revert_bike.py
```

### `transform_bike_reverse.py`

바이크 변형 방향을 반대로 확인하거나, 역방향 변형 테스트에 쓰는 보조 스크립트입니다.

## 바이크 주행

### `bike_teleop.py`

바이크 모드에서 바퀴 속도 명령을 보내는 텔레옵 스크립트입니다. 바퀴 모터는 `dynamixel_hardware.yaml`에서 velocity mode로 관리합니다.

```bash
ros2 run biped_bike_robot bike_teleop.py
```

키 조작:

- `w`: 전진 속도를 0.5 rad/s씩 증가
- `s`: 감속 후 후진 속도를 0.5 rad/s씩 증가
- `a`, `d`: 좌·우 회전 성분 조절
- `q` 또는 `Space`: 즉시 정지
- `Ctrl-C`: 정지 명령을 보낸 뒤 종료

기본 최대 바퀴 속도는 `2.0 rad/s`입니다. 실물 브릿지는 ID 7과 14를
velocity mode로 초기화하고 앞의 두 속도값을 전달합니다. 명령이 0.5초 이상
끊기면 watchdog이 두 바퀴를 자동 정지합니다. 첫 시험은 로봇을 들어 바퀴가
바닥에 닿지 않은 상태에서 `w`를 한 번만 눌러 방향을 확인합니다.

더 낮은 속도로 텔레옵을 실행하려면:

```bash
ros2 run biped_bike_robot bike_teleop.py --ros-args \
  -p speed_step:=0.25 \
  -p max_wheel_speed:=1.0
```

## 실기 브릿지

### `dxl_joint_state_bridge.py`

ROS 명령을 Dynamixel XL430 명령으로 변환하는 실기 브릿지입니다.

받는 명령:

- `/joint_states`: RViz GUI 방향 확인용 위치 명령
- `/joint_trajectory_controller/joint_trajectory`: walker/ready/transform 스크립트의 trajectory 명령

하는 일:

- `config/dynamixel_hardware.yaml`에서 모터 ID, joint 이름, 방향, gain, mode를 읽습니다.
- URDF 기준 radian 값을 Dynamixel tick으로 변환합니다.
- 위치 모터에는 `Goal Position`을 sync write합니다.
- 옵션을 켜면 Dynamixel telemetry를 CSV로 기록합니다.
- `JointTrajectory`의 점 사이를 8ms 주기로 선형 보간합니다. 첫 점은 모터의 현재 위치에서 시작하므로, 도착 시간까지 기다렸다가 목표로 한 번에 점프하지 않습니다.
- 보행용 전역 명령 한도는 `max_abs_position_rad`를 사용하지만, 180도 회전이 필요한 `arm_base_yaw_jnt`는 하드웨어 YAML의 관절별 한도 `3.14159 rad`를 우선 적용합니다.
- `/wheel_velocity_controller/commands`를 받아 두 실물 바퀴의 Goal Velocity에 sync write하고, 명령 timeout 시 속도를 0으로 만듭니다.
- `startup_ready_posture_on_start:=true`를 켜면 시작 시 hip pitch를 앞으로 더 기울인 ready 자세와 `startup_shoulder_pitch_deg` 어깨 각도를 바로 보냅니다. 실물 보행 기본값은 `startup_forward_lean_deg:=10.0`, `startup_shoulder_pitch_deg:=-70.0`이며 팔꿈치 pitch는 0도입니다.

브릿지는 보통 직접 실행하지 않고 `hardware_display.launch.py`로 실행합니다.

#### OpenCR IMU 데이터 형식과 강화학습 입력 기준

현재 실제 로봇 제어 중 IMU는 OpenCR 내장 IMU를 사용합니다. OpenCR은 Dynamixel TTL 브리지 역할을 하면서, 가상 Dynamixel ID `200`으로 IMU 값을 응답합니다. PC 쪽 `dxl_joint_state_bridge.py`가 이 값을 읽어서 ROS 표준 메시지인 `sensor_msgs/Imu`로 변환해 `/opencr/imu`에 publish합니다.

실행 경로:

```bash
ros2 launch biped_bike_robot hardware_display.launch.py \
  enable_opencr_imu:=true \
  enable_imu_tf:=true \
  use_joint_state_gui:=false \
  publish_present_joint_states:=true \
  enable_joint_state_commands:=false \
  enable_trajectory_commands:=true \
  startup_ready_posture_on_start:=true \
  center_on_start:=false
```

확인은 다음처럼 합니다.

```bash
ros2 topic echo /opencr/imu
ros2 run tf2_ros tf2_echo world base_link
```

웹 컨트롤러의 하드웨어 ON 버튼도 위 설정을 기본으로 실행합니다.

OpenCR 스케치 `arduino/opencr_dxl_bridge_with_imu/opencr_dxl_bridge_with_imu.ino`는 주소 `100`부터 `68 byte`짜리 IMU 블록을 만듭니다. PC에서는 Dynamixel Protocol 2.0 read로 이 블록을 읽습니다.

| Offset | Type | 이름 | 단위/의미 |
|---:|---|---|---|
| 100 | `uint32` | `time_ms` | OpenCR 부팅 후 ms |
| 104 | `float` | `qw` | OpenCR IMU quaternion w |
| 108 | `float` | `qx` | OpenCR IMU quaternion x |
| 112 | `float` | `qy` | OpenCR IMU quaternion y |
| 116 | `float` | `qz` | OpenCR IMU quaternion z |
| 120 | `float` | `roll_deg` | roll, degree |
| 124 | `float` | `pitch_deg` | pitch, degree |
| 128 | `float` | `yaw_deg` | yaw, degree |
| 132 | `float` | `gyro_x_dps` | gyro x, degree/sec |
| 136 | `float` | `gyro_y_dps` | gyro y, degree/sec |
| 140 | `float` | `gyro_z_dps` | gyro z, degree/sec |
| 144 | `float` | `acc_x_g` | accel x, g |
| 148 | `float` | `acc_y_g` | accel y, g |
| 152 | `float` | `acc_z_g` | accel z, g |
| 156 | `int16` | `gyro_x_adc` | raw gyro x |
| 158 | `int16` | `gyro_y_adc` | raw gyro y |
| 160 | `int16` | `gyro_z_adc` | raw gyro z |
| 162 | `int16` | `acc_x_adc` | raw accel x |
| 164 | `int16` | `acc_y_adc` | raw accel y |
| 166 | `int16` | `acc_z_adc` | raw accel z |

PC 쪽에서는 이 블록을 다음 형식으로 unpack합니다.

```python
struct.unpack("<I13f6h", bytes(data))
```

`/opencr/imu`는 `sensor_msgs/Imu`입니다. 강화학습에서 ROS 토픽을 바로 쓰면 이 형식을 기준으로 받으면 됩니다.

```text
header.frame_id: body_link
orientation: quaternion, x/y/z/w
angular_velocity: rad/s
linear_acceleration: m/s^2
```

변환 규칙은 다음과 같습니다.

| ROS 필드 | 원본 OpenCR 값 | 변환 |
|---|---|---|
| `orientation.w/x/y/z` | `qw/qx/qy/qz` | 그대로 사용 |
| `angular_velocity.x/y/z` | `gyro_*_dps` | `deg/s * pi / 180` |
| `linear_acceleration.x/y/z` | `acc_*_g` | `g * 9.80665` |
| `orientation_covariance` | 고정값 | 대각선 `0.0025` |
| `angular_velocity_covariance` | 고정값 | 대각선 `0.02` |
| `linear_acceleration_covariance` | 고정값 | 대각선 `0.04` |

중요한 점은 `/opencr/imu`의 quaternion은 OpenCR 보드 기준 원본 자세라는 것입니다. 보드가 로봇 등 뒤에 수직으로 달려 있어서, 이 값을 그대로 쓰면 로봇의 roll/pitch/yaw 감각과 다르게 보입니다.

로봇 기준 자세 시각화는 `imu_base_tf.py`가 담당합니다. 이 노드는 `/opencr/imu`를 받아서 `world -> base_link` TF를 publish합니다.

| 파라미터 | 기본값 | 의미 |
|---|---:|---|
| `imu_mount_roll_deg` | `-90.0` | OpenCR 보드 장착 roll 보정 |
| `imu_mount_pitch_deg` | `0.0` | 장착 pitch 보정 |
| `imu_mount_yaw_deg` | `0.0` | 장착 yaw 보정 |
| `imu_rpy_remap` | `YRp` | roll/pitch/yaw 축 재매핑. 대문자는 부호 반전 |
| `imu_zero_yaw_on_start` | `true` | 켤 때 yaw를 정면 0으로 잡음 |
| `imu_yaw_zero_samples` | `10` | 처음 10개 샘플 평균으로 yaw zero 계산 |
| `imu_pivot_x/y/z` | `-0.066549, -0.076779, 0.018299` | base_link 중앙 기준 회전 pivot 보정 |

즉 RViz와 웹 뷰어에서 로봇이 기울어지는 자세는 원본 `/opencr/imu`가 아니라 보정된 `/tf`의 `world -> base_link`를 보고 있습니다. 강화학습에서 로봇 몸통 기준 roll/pitch/yaw를 쓰고 싶으면 이 보정된 TF 또는 동일한 보정식을 적용한 quaternion을 쓰는 것이 안전합니다.

강화학습 observation 추천:

```text
base_orientation_quat: [x, y, z, w]      # 보정된 world -> base_link quaternion 권장
base_angular_velocity: [wx, wy, wz]      # /opencr/imu angular_velocity, rad/s
base_linear_accel: [ax, ay, az]          # /opencr/imu linear_acceleration, m/s^2
joint_position: 현재 /joint_states position
joint_velocity: 현재 /joint_states velocity가 안정적으로 읽히면 사용
```

정책 입력으로 yaw 절대각이 필요 없으면 quaternion 대신 gravity vector를 body frame으로 회전한 값이나 roll/pitch만 쓰는 편이 더 안정적입니다. yaw는 시작할 때 `imu_zero_yaw_on_start:=true`로 0을 잡지만, 장시간 운용에서는 IMU yaw drift가 생길 수 있습니다.

주의할 점:

- `/opencr/imu`의 `linear_acceleration`에는 중력 성분이 포함됩니다. 서 있을 때도 한 축에 약 `9.8 m/s^2` 크기가 나오는 것이 정상입니다.
- 로봇이 모터를 움직이는 중에도 IMU는 같은 OpenCR-Dynamixel 포트로 읽습니다. `enable_opencr_imu:=true`일 때 bridge가 주기적으로 가상 ID `200`을 읽기 때문에 로봇 동작과 동시에 사용할 수 있습니다.
- IMU publish rate 기본값은 `30 Hz`입니다. 더 빠르게 읽으면 DXL 제어 주기와 버스 부하에 영향을 줄 수 있으니, RL 로깅은 처음에는 `30 Hz` 기준으로 맞추는 것이 좋습니다.
- 실험 전에는 `ros2 topic hz /opencr/imu`로 실제 주기를 확인합니다.

IMU 숫자 형식을 단독으로 보고 싶을 때만 `arduino/opencr_imu_stream/opencr_imu_stream.ino`를 올립니다. 이 모드는 USB serial에 CSV를 출력하므로 Dynamixel 제어와 동시에 쓰는 모드가 아닙니다.

```bash
python3 src/biped_bike_robot/scripts/opencr_imu_reader.py --port /dev/opencr --rows 20
```

CSV 컬럼은 다음 순서입니다.

```text
time_ms,qw,qx,qy,qz,roll_deg,pitch_deg,yaw_deg,gyro_x_dps,gyro_y_dps,gyro_z_dps,acc_x_g,acc_y_g,acc_z_g,gyro_x_adc,gyro_y_adc,gyro_z_adc,acc_x_adc,acc_y_adc,acc_z_adc
```

실제 로봇 제어로 돌아가려면 다시 `arduino/opencr_dxl_bridge_with_imu/opencr_dxl_bridge_with_imu.ino`를 OpenCR에 업로드해야 합니다.

### `web_control.py`

실물 테스트용 로컬 웹 인터페이스입니다. 브라우저 버튼으로 하드웨어 브릿지를 켜고 끄거나, 검증된 보행/변신 명령을 실행합니다.

```bash
ros2 run biped_bike_robot web_control.py
```

실행 후 브라우저에서 엽니다.

```text
http://127.0.0.1:8080
```

`ros2 run`에서 새 스크립트를 못 찾으면 워크스페이스 루트에서 직접 실행합니다.

```bash
python3 src/biped_bike_robot/scripts/web_control.py
```

버튼 동작:

- `Hardware ON`: 아래 하드웨어 브릿지 명령을 실행하고 계속 유지합니다.
- `Hardware OFF`: 실행 중인 하드웨어 브릿지를 종료합니다.
- `Run Walk`: 입력한 `cycles` 값으로 실기 보행 보정 명령을 실행합니다.
- `Run Transform`: 입력한 `sec/stage` 값으로 `transform_bike.py`를 실행합니다.
- `Teleop ON/OFF`: 바이크 모드 키보드 주행 publisher를 켜고 끕니다.
- `Set Speed`: 키보드 주행 속도를 `0.1`에서 `5.0 rad/s` 사이에서 지정합니다.
- 키보드 주행: `W/S`는 전진/후진, `A/D`는 좌/우 회전, `Q` 또는 `Space`는 바퀴 정지입니다. 웹 페이지에 현재 눌린 키와 현재 속도가 표시됩니다.

웹 패널의 `Hardware ON` 명령:

```bash
ros2 launch biped_bike_robot hardware_display.launch.py \
  enable_opencr_imu:=true \
  enable_imu_tf:=true \
  use_joint_state_gui:=false \
  publish_present_joint_states:=true \
  enable_joint_state_commands:=false \
  enable_trajectory_commands:=true \
  startup_ready_posture_on_start:=true \
  center_on_start:=false
```

웹 패널의 `Run Walk` 명령:

```bash
ros2 run biped_bike_robot ik_walker.py --ros-args \
  -p num_cycles:=1 \
  -p support_hip_roll_lift_deg:=20.0 \
  -p support_ankle_roll_lift_deg:=10.0 \
  -p support_ankle_roll_lift_sign:=1.0 \
  -p pelvis_pitch_forward_lift_deg:=30.0 \
  -p pelvis_pitch_forward_lift_sign:=1.0 \
  -p trajectory_time_scale:=4.0
```

웹 패널의 `Run Transform` 명령:

```bash
ros2 run biped_bike_robot transform_bike.py --ros-args \
  -p stage_duration_sec:=5.0
```

웹 패널의 바이크 주행 명령은 별도 터미널 teleop 대신 브라우저 키 입력을 받아 `/wheel_velocity_controller/commands`로 직접 publish합니다.

## URDF 보정

### `patch_urdf.py`

SolidWorks export URDF를 ROS 2/Gazebo에서 쓰기 좋게 보정하는 스크립트입니다. mesh 경로, joint/controller 연동, Gazebo 사용에 필요한 부분을 정리할 때 사용합니다.

## 하드웨어 기준

현재 실기 기준:

- Dynamixel `XL430-W250`
- TTL bus
- Protocol `2.0`
- Baudrate `1000000`
- OpenCR USB-to-Dynamixel passthrough
- `2048 tick == URDF 0 rad`
- 위치 관절 Operating Mode `3`
- 바퀴 모터 Operating Mode `1`

모터 ID, 방향, gain, telemetry 주소는 `config/dynamixel_hardware.yaml`에서 관리합니다.

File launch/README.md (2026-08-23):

# Launch Files

이 폴더는 RViz 표시, Gazebo 시뮬레이션, 실제 Dynamixel 하드웨어 연동 런치를 담고 있습니다.

## 공통 준비

```bash
cd ~/biped_bike_ws
source /opt/ros/jazzy/setup.bash
colcon build --packages-select biped_bike_robot
source install/setup.bash
```

## `display.launch.py`

URDF를 RViz에서 확인하고 `joint_state_publisher_gui` 슬라이더로 관절을 움직여 보는 순수 표시용 런치입니다. 실제 모터에는 연결하지 않습니다.

```bash
ros2 launch biped_bike_robot display.launch.py
```

실행 노드:

- `robot_state_publisher`
- `joint_state_publisher_gui`
- `rviz2`

## `gazebo.launch.py`

Gazebo에서 로봇과 `ros2_control` controller를 실행합니다. IK walker, ready posture, transform script를 시뮬레이션에서 먼저 검증할 때 사용합니다.

```bash
ros2 launch biped_bike_robot gazebo.launch.py
```

보행 실행:

```bash
ros2 run biped_bike_robot ik_walker.py
```

실행 구성:

- `ros_gz_sim`
- `robot_state_publisher`
- `ros_gz_bridge` clock bridge
- `joint_state_broadcaster`
- `joint_trajectory_controller`
- `wheel_velocity_controller`

## `hardware_display.launch.py`

RViz, GUI, Dynamixel bridge를 함께 실행하는 실제 하드웨어 연동 런치입니다. OpenCR에는 `arduino/opencr_usb_to_dxl/opencr_usb_to_dxl.ino`가 올라가 있어야 하고, Dynamixel Wizard나 Arduino Serial Monitor가 `/dev/ttyACM0`을 잡고 있으면 안 됩니다.

실기 브릿지는 `JointTrajectory`를 현재 모터 위치부터 8ms 주기로 선형
보간합니다. 따라서 `ready_posture.py`의 3초 도착 시간과 워커의 시작 전환
시간이 실제 모터에도 적용됩니다. 단, 아래의 `center_on_start` 중앙정렬은
기존처럼 런치 직후 즉시 전송됩니다.

기본 실행:

```bash
ros2 launch biped_bike_robot hardware_display.launch.py
```

기본값으로 `center_on_start:=true`입니다. 실행하면 위치 모터에 2048 tick 정자세 명령을 보냅니다.

### 방향 확인 모드

작은 범위만 허용하고 GUI 슬라이더를 실제 모터로 보냅니다.

```bash
ros2 launch biped_bike_robot hardware_display.launch.py \
  max_abs_position_rad:=0.1 \
  enable_joint_state_commands:=true \
  enable_trajectory_commands:=false
```

### 실기 보행 모드

GUI 명령은 끄고 `JointTrajectory`만 받습니다.

터미널 1:

```bash
ros2 launch biped_bike_robot hardware_display.launch.py \
  max_abs_position_rad:=2.2 \
  center_on_start:=false \
  startup_ready_posture_on_start:=true \
  startup_forward_lean_deg:=10.0 \
  startup_shoulder_pitch_deg:=-70.0 \
  enable_joint_state_commands:=false \
  enable_trajectory_commands:=true
```

터미널 2:

```bash
ros2 run biped_bike_robot ready_posture.py

ros2 run biped_bike_robot ik_walker.py
```

첫 실물 검증은 로봇을 지지한 상태에서 다음처럼 한 사이클만 5배 느리게
실행합니다.

```bash
ros2 run biped_bike_robot ik_walker.py --ros-args \
  -p num_cycles:=1 \
  -p trajectory_time_scale:=5.0 \
  -p startup_duration_sec:=3.0
```

### 모터 로그 모드

Dynamixel telemetry를 CSV로 저장합니다. 기본 저장 위치는 아래입니다.

```text
src/biped_bike_robot/motor_logs/dxl_telemetry_YYYYMMDD_HHMMSS.csv
```

전체 모터를 10초간 5Hz로 기록:

```bash
ros2 launch biped_bike_robot hardware_display.launch.py \
  log_telemetry:=true \
  max_abs_position_rad:=2.2 \
  center_on_start:=false \
  startup_ready_posture_on_start:=true \
  startup_forward_lean_deg:=10.0 \
  startup_shoulder_pitch_deg:=-70.0 \
  enable_joint_state_commands:=false \
  enable_trajectory_commands:=true
```

롤축 4개만 20초간 10Hz로 기록:

```bash
ros2 launch biped_bike_robot hardware_display.launch.py \
  log_telemetry:=true \
  telemetry_rate_hz:=10.0 \
  telemetry_duration_sec:=20.0 \
  telemetry_motor_ids:=2,6,9,13 \
  max_abs_position_rad:=2.2 \
  center_on_start:=false \
  startup_ready_posture_on_start:=true \
  startup_forward_lean_deg:=10.0 \
  startup_shoulder_pitch_deg:=-70.0 \
  enable_joint_state_commands:=false \
  enable_trajectory_commands:=true
```

로그 컬럼:

- `goal_tick`: 브릿지가 마지막으로 보낸 목표 위치
- `present_position_tick`: 실제 encoder 위치
- `position_error_tick`: `goal_tick - present_position_tick`
- `present_pwm_percent`: 모터 출력 PWM 비율
- `present_load_percent`: XL430 내부 추정 load
- `voltage_v`: 입력 전압
- `temperature_c`: 모터 온도

판단 기준:

- `position_error_tick`이 커지고 `present_pwm_percent`가 90~100%에 가까우면 토크/기구 한계 가능성이 큽니다.
- `position_error_tick`이 커지는 순간 `voltage_v`가 크게 떨어지면 전원/배선 문제가 의심됩니다.
- `present_pwm_percent`가 낮은데 오차가 크면 gain, profile, 명령 주기, 기구 유격을 확인합니다.

## `hardware_display.launch.py` 파라미터

- `torque_on_start`  
  기본값 `true`. 시작 시 위치 모터 torque를 켭니다.

- `center_on_start`  
  기본값 `true`. 시작 시 위치 모터를 2048 tick으로 보냅니다. 현재 자세가 많이 틀어져 있으면 갑자기 움직일 수 있으므로 로봇을 잡거나 지지대에 올린 상태에서 켭니다.

- `startup_ready_posture_on_start`  
  기본값 `false`. 시작 시 2048 tick 영점 대신 앞으로 살짝 기울어진 ready 자세를 보냅니다. 실물 보행 시작 전에는 `center_on_start:=false`와 함께 켭니다.

- `startup_forward_lean_deg`  
  기본값 `5.0`. `startup_ready_posture_on_start`에서 좌우 hip pitch에 추가하는 전방 기울임입니다. 현재 실물 보행 기본 예시는 `10.0`을 사용합니다.

- `startup_shoulder_pitch_deg`  
  기본값 `-70.0`. `startup_ready_posture_on_start`에서 어깨 pitch를 뒤쪽으로 접어 유지하는 각도입니다. 팔꿈치 pitch는 0도로 유지합니다.

- `max_abs_position_rad`  
  기본값 `0.35`. 이 절대값보다 큰 위치 명령은 무시합니다. 실기 보행에서는 보통 `2.2` 정도로 올립니다.

- `log_joint_states`  
  기본값 `true`. `/joint_states`에서 받은 joint 명령을 터미널에 출력합니다.

- `enable_joint_state_commands`  
  기본값 `true`. GUI 슬라이더 `/joint_states` 명령을 실제 모터로 보냅니다.

- `enable_trajectory_commands`  
  기본값 `true`. walker/ready/transform 스크립트의 `JointTrajectory` 명령을 실제 모터로 보냅니다.

- `enable_velocity_commands`  
  기본값 `true`. bike teleop의 바퀴 속도 명령을 ID 7과 14에 전달합니다.

- `max_wheel_velocity_rad_s`  
  기본값 `2.0`. 실물 바퀴별 속도 명령의 절대 상한입니다.

- `wheel_command_timeout_sec`  
  기본값 `0.5`. 이 시간 동안 새 속도 명령이 없으면 두 바퀴를 자동 정지합니다.

- `log_telemetry`  
  기본값 `false`. Dynamixel telemetry CSV 기록을 켭니다.

- `telemetry_log_path`  
  기본값 빈 문자열. 비워두면 `src/biped_bike_robot/motor_logs`에 자동 파일명으로 저장합니다.

- `telemetry_rate_hz`  
  기본값 `5.0`. telemetry 기록 주기입니다.

- `telemetry_duration_sec`  
  기본값 `10.0`. 이 시간이 지나면 telemetry 기록을 멈춥니다. `0`이면 종료할 때까지 계속 기록합니다.

- `telemetry_motor_ids`  
  기본값 빈 문자열. 비워두면 모든 활성 모터를 기록합니다. 예: `2,6,9,13`.

## 안전 메모

- 실제 로봇 테스트는 처음에는 반드시 로봇을 손으로 잡거나 지지대에 올려서 합니다.
- `center_on_start`는 편하지만 시작 즉시 정자세 명령이 나갑니다.
- Dynamixel Wizard, Arduino IDE Serial Monitor, 다른 ROS 노드가 같은 포트를 열면 브릿지가 실패합니다.
- 로그 CSV는 커질 수 있으므로 기본 제한을 유지하고 필요한 모터만 `telemetry_motor_ids`로 골라 기록합니다.

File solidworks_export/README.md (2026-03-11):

# SolidWorks Export 폴더

이 폴더에 SolidWorks URDF Exporter로 내보낸 **원본 파일**을 넣으세요.

## 구조
```
solidworks_export/
├── urdf/
│   └── <패키지명>.urdf    ← SolidWorks에서 내보낸 URDF
└── meshes/
    └── *.STL              ← SolidWorks에서 내보낸 메시 파일들
```

## 사용법

1. SolidWorks 익스포트 결과물의 `urdf/`와 `meshes/` 폴더를 여기에 **통째로 덮어쓰기**
2. 패키지 루트에서 패치 스크립트 실행:
   ```bash
   cd ~/biped_bike_ws/src/biped_bike_robot
   python3 scripts/patch_urdf.py
   ```
3. 빌드:
   ```bash
   cd ~/biped_bike_ws
   colcon build && source install/setup.bash
   ```

> ⚠️ 이 폴더의 파일을 **직접 수정하지 마세요**.
> 수정이 필요하면 `scripts/patch_urdf.py`에 패치 규칙을 추가하세요.

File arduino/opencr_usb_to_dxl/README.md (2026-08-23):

# OpenCR USB to Dynamixel TTL

This Arduino sketch turns an OpenCR board into a simple U2D2-style passthrough:

```text
PC /dev/ttyACM0 <-> OpenCR USB Serial <-> OpenCR Serial3 <-> Dynamixel TTL bus
```

Use it with `dxl_joint_state_bridge.py` or Dynamixel Wizard. Only one PC program
can open `/dev/ttyACM0` at a time.

## Upload

1. Open `opencr_usb_to_dxl.ino` in Arduino IDE.
2. Select `OpenCR Board`.
3. Select the OpenCR serial port.
4. Upload the sketch.
5. Close Arduino Serial Monitor and Dynamixel Wizard before running ROS.

## ROS Test

```bash
source /opt/ros/jazzy/setup.bash
colcon build --packages-select biped_bike_robot
source install/setup.bash
ros2 launch biped_bike_robot hardware_display.launch.py max_abs_position_rad:=0.1
```

Move one slider by a small amount, such as `+0.05 rad`. If the real robot moves
in the same direction as RViz, keep `direction: 1` in `dynamixel_hardware.yaml`.
If it moves in the opposite direction, set that joint to `direction: -1`.

## Notes

- Do not print debug logs to `Serial`; it corrupts Dynamixel packets.
- The sketch powers the OpenCR Dynamixel port with `BDPIN_DXL_PWR_EN`.
- USB baudrate is mirrored to the Dynamixel TTL port. The default is `1000000`.
- Keep the robot supported while testing. A motor far from tick `2048` can move
  suddenly when torque is enabled.

## Built-in IMU While Running ROS

To read the OpenCR built-in IMU while controlling Dynamixels, upload this
bridge instead:

```text
../opencr_dxl_bridge_with_imu/opencr_dxl_bridge_with_imu.ino
```

It keeps normal USB-to-Dynamixel forwarding, and answers Dynamixel Protocol 2.0
read requests to virtual ID `200` with OpenCR IMU data.

Run hardware with:

```bash
ros2 launch biped_bike_robot hardware_display.launch.py \
  enable_opencr_imu:=true \
  opencr_imu_rate_hz:=30.0
```

Check the ROS IMU topic:

```bash
ros2 topic echo /opencr/imu
```

The bridge publishes `sensor_msgs/Imu`. Quaternion comes from the OpenCR IMU
filter, gyro is converted from deg/s to rad/s, and acceleration is converted
from g to m/s^2.

## Built-in IMU Format Check Only

The OpenCR USB serial cannot carry Dynamixel packets and debug text at the same
time. To inspect the OpenCR built-in IMU, temporarily upload:

```text
../opencr_imu_stream/opencr_imu_stream.ino
```

Then read CSV rows from the PC:

```bash
python3 src/biped_bike_robot/scripts/opencr_imu_reader.py --port /dev/opencr --rows 20
```

CSV columns:

```text
time_ms,qw,qx,qy,qz,roll_deg,pitch_deg,yaw_deg,gyro_x_dps,gyro_y_dps,gyro_z_dps,acc_x_g,acc_y_g,acc_z_g,gyro_x_adc,gyro_y_adc,gyro_z_adc,acc_x_adc,acc_y_adc,acc_z_adc
```

Re-upload `opencr_usb_to_dxl.ino` before running ROS hardware control again.

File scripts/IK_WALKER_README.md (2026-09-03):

# IK Walker Technical Notes

`ik_walker.py` generates walking trajectories for `biped_bike_robot`.
It uses a sinusoidal gait pattern, lateral center-of-mass shifting, and
analytical 6-DOF leg IK to produce a 17-DOF `JointTrajectory`.

## Architecture

```text
IKWalkerNode (ROS 2)
  WalkingParam -> IKWalkerEngine -> JointTrajectory
```

| Module | Role |
|---|---|
| `WalkingParam` | Physical robot dimensions, stance, stride, timing, and lift parameters |
| `IKWalkerEngine` | Sinusoidal gait phase generation and leg IK |
| `analytical_ik_leg()` | 6-DOF leg inverse kinematics |
| `IKWalkerNode` | ROS 2 publisher for `/joint_trajectory_controller/joint_trajectory` |

## Core Idea

The controller shifts the body laterally before lifting a foot, so the center of
mass moves over the support foot. The pelvis is kept level as much as possible,
and the legs absorb most of the side-to-side motion.

The gait cycle is split into four phases:

| Phase | Meaning |
|---|---|
| DSP start | Both feet support the robot while weight transfer begins |
| Left SSP | Left foot swings while the right foot supports |
| DSP middle | Both feet support the robot while weight transfer reverses |
| Right SSP | Right foot swings while the left foot supports |

## Robot-Specific Notes

- Forward motion is negative X in the current robot frame, so forward
  `x_move_amplitude` values are negative.
- The hip spacing is wider than many small humanoid examples, so the default
  lateral shift is intentionally large.
- `JOINT_AXIS_DIR` maps analytical IK output into the joint axes exported in the
  robot URDF.

## Run

```bash
ros2 run biped_bike_robot ik_walker.py
```

The hardware-tested gait is the default profile inside `WalkingParam`, so the
web controller and direct execution use the same values. Only run-specific
settings such as the number of cycles need to be supplied:

```bash
ros2 run biped_bike_robot ik_walker.py --ros-args \
  -p num_cycles:=1
```

The gait does not add hardware-only hip, ankle, or pelvis corrections after
IK. Foot spacing, center-of-mass motion, and swing height are expressed as
Cartesian foot targets and solved by the same IK path.

The analytical IK and lateral `y_swap` path keep their original axis mapping.
After IK, an independent hardware backlash correction adds left hip `-3` /
ankle `+3` degrees and right hip `+3` / ankle `-3` degrees. Changing this
correction therefore does not change the underlying IK trajectory or foot
targets. After the last cycle, only this 3-degree correction is interpolated
out over two seconds; the base IK roll remains intact.

The default posture also adds 10 degrees of forward hip pitch after IK (left
`-10`, right `+10` degrees in hardware command coordinates). This corrects the
backward body lean without changing the foot targets or ankle pitch trajectory.

## References

This controller was designed while studying open-source humanoid gait
controllers and analytical leg IK implementations. Keep third-party source code
and license notices in the repository's reference or notice material if any
third-party code is distributed with a release.

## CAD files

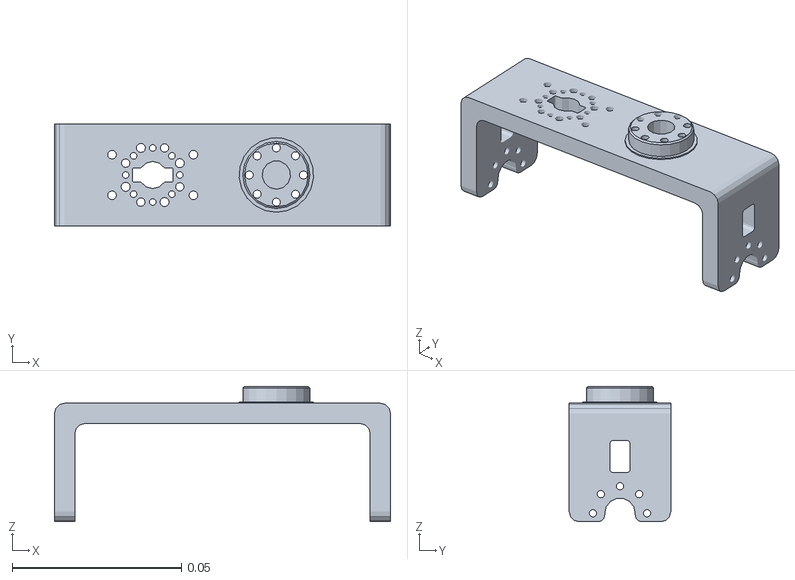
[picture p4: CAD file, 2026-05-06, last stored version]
meshes/r_hip_yaw.STL
0.0992 x 0.03 x 0.04

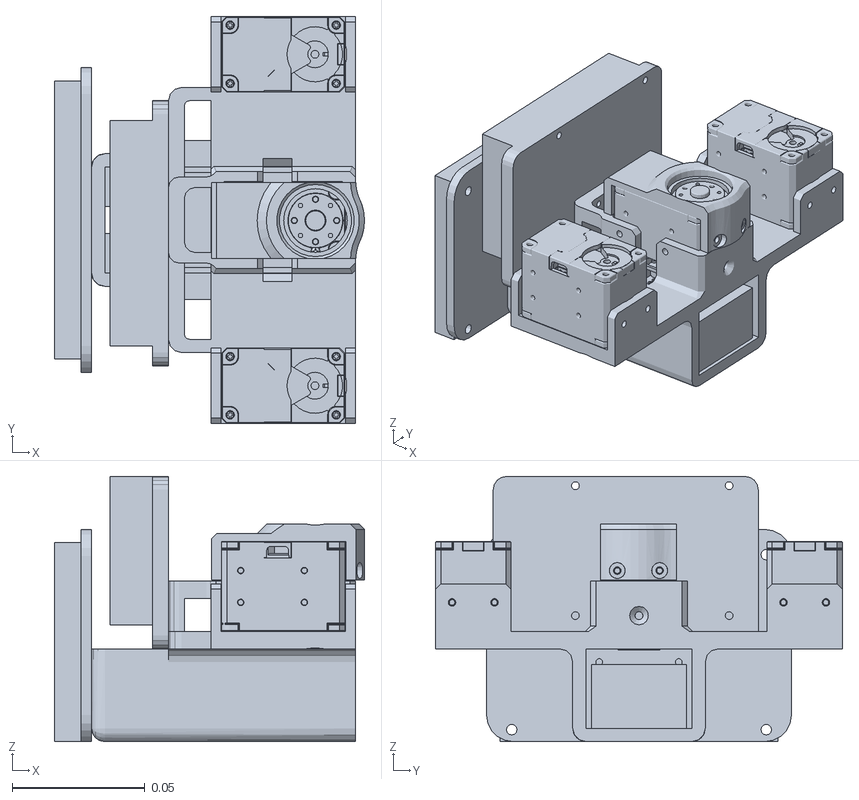
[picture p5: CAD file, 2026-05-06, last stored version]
meshes/base_link.STL
0.117 x 0.154 x 0.1

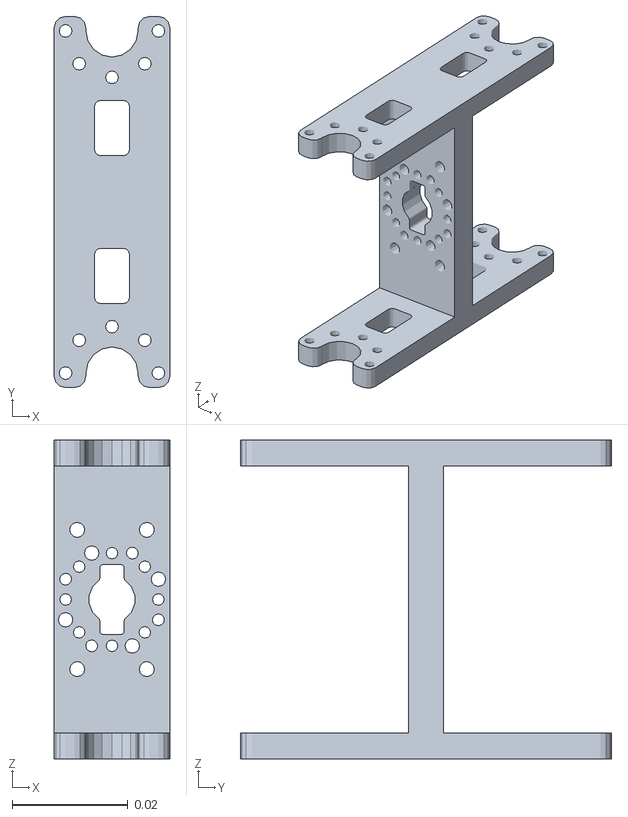
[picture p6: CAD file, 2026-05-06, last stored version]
meshes/l_hip_pitch.STL
0.02 x 0.064 x 0.055

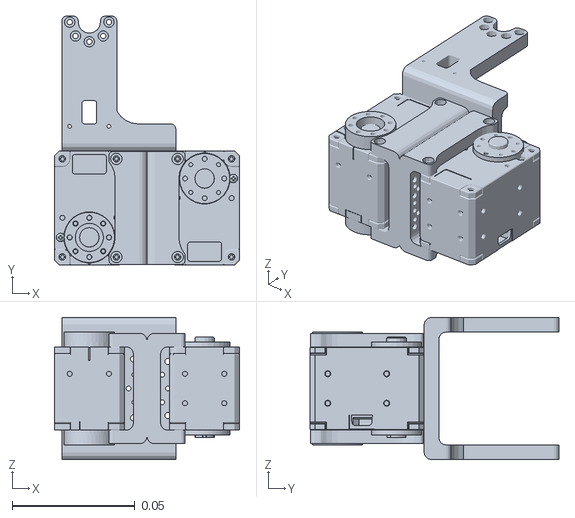
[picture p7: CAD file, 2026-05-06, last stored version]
meshes/r_knee_pitch.STL
0.0755 x 0.102 x 0.058

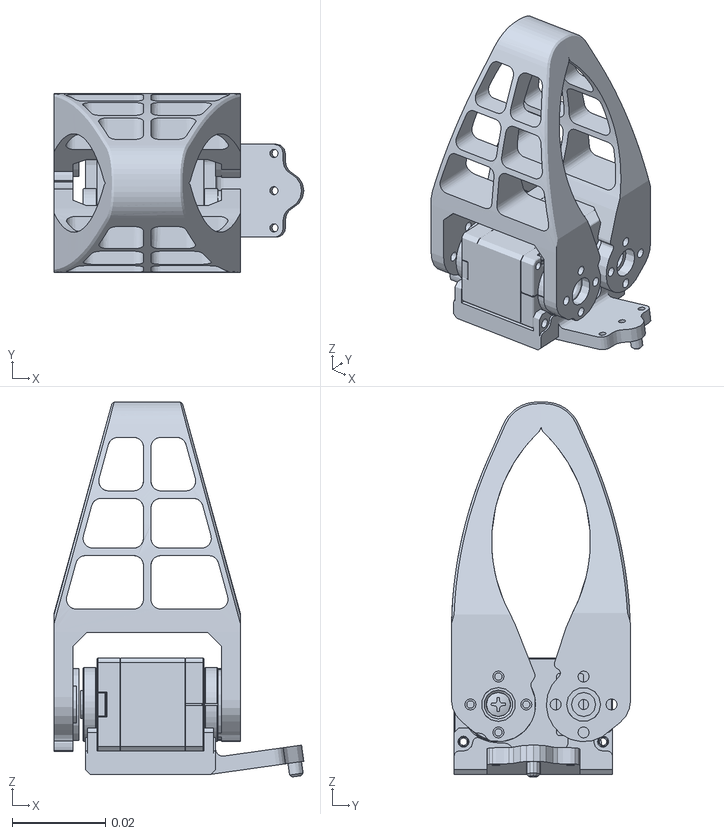
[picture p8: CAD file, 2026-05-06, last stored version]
meshes/arm_wrist_roll.STL
0.0537 x 0.0385 x 0.0806

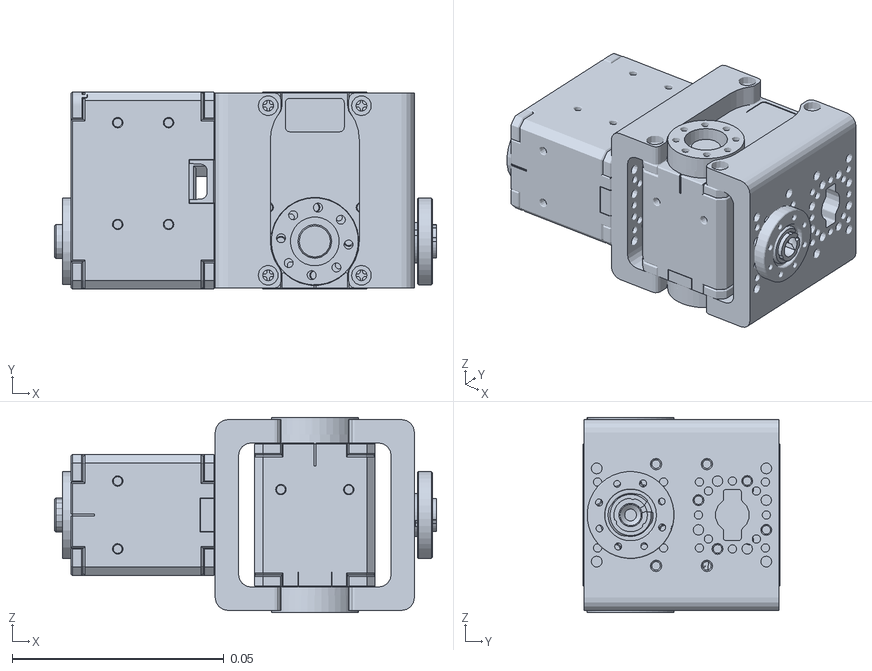
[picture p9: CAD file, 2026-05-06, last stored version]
meshes/l_ankle_pitch.STL
0.0901 x 0.0465 x 0.046

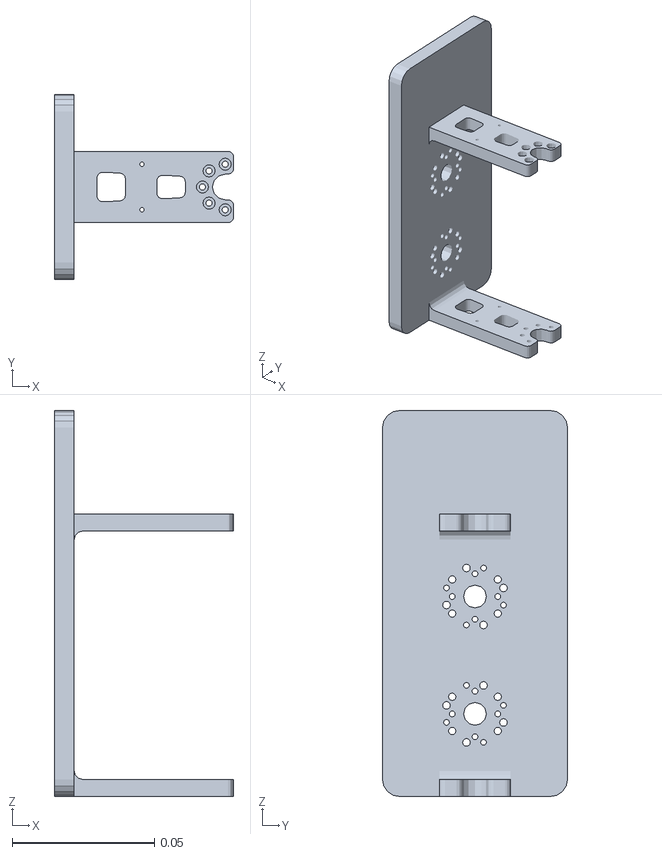
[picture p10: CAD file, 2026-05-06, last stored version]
meshes/r_foot_roll.STL
0.063 x 0.065 x 0.136

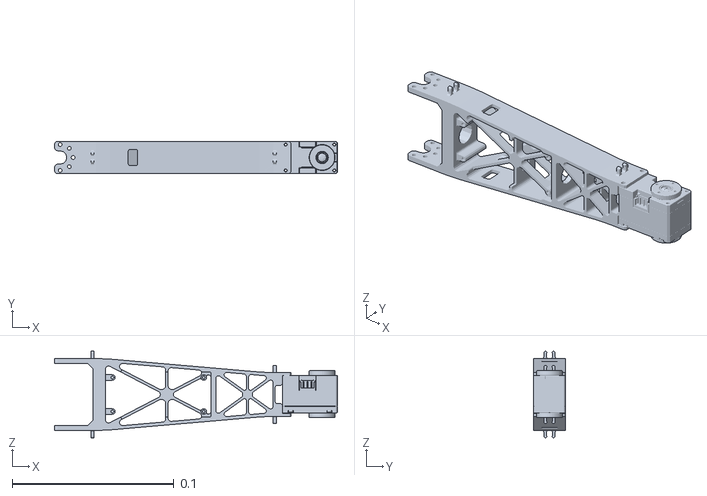
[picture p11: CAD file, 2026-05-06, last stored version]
meshes/arm_elbow_pitch.STL
0.175 x 0.02 x 0.0535

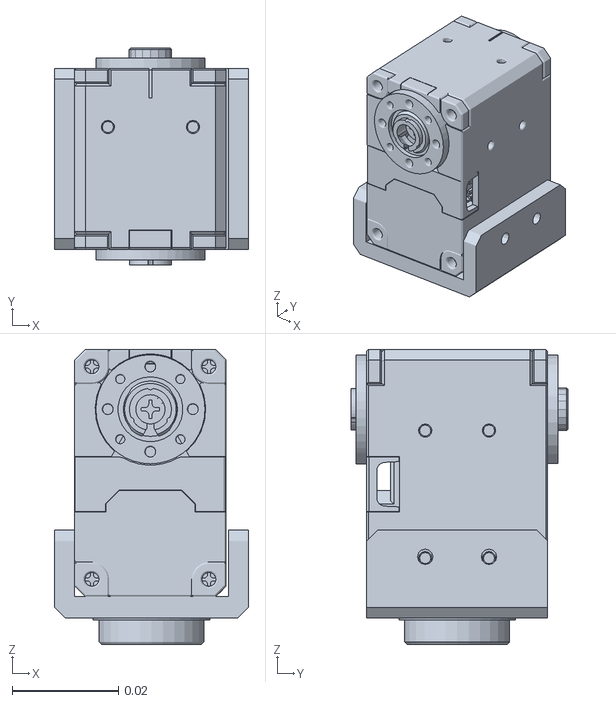
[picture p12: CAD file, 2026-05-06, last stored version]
meshes/arm_base_yaw.STL
0.0365 x 0.0409 x 0.0555

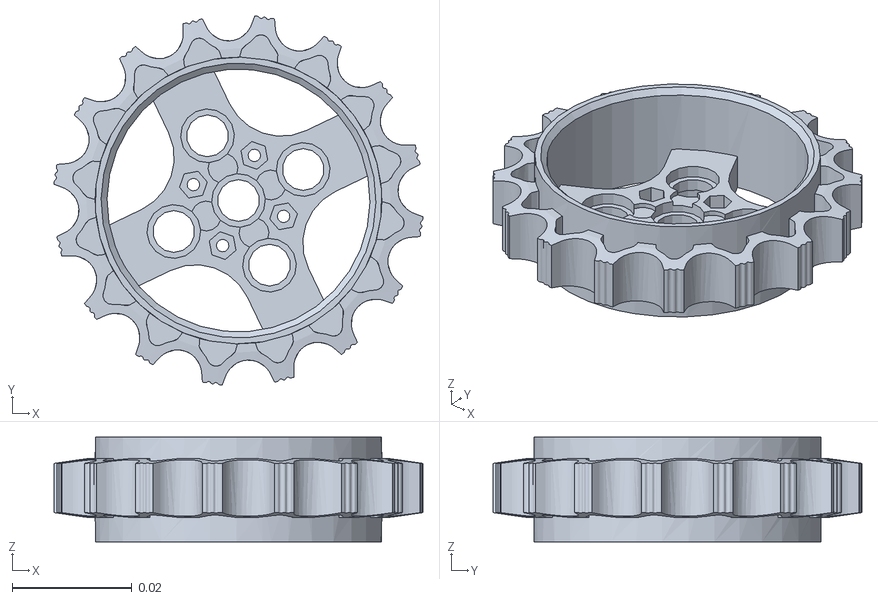
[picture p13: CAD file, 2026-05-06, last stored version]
meshes/l_knee_pitch_wheel.STL
0.0618 x 0.0618 x 0.0175

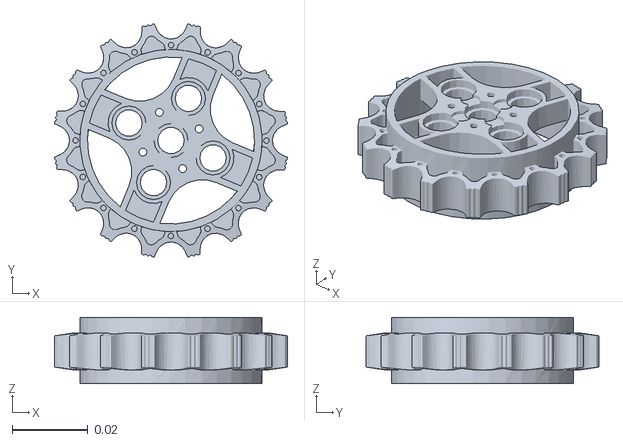
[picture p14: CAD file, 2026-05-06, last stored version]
meshes/r_knee_pitch_wheel.STL
0.0614 x 0.0614 x 0.0175

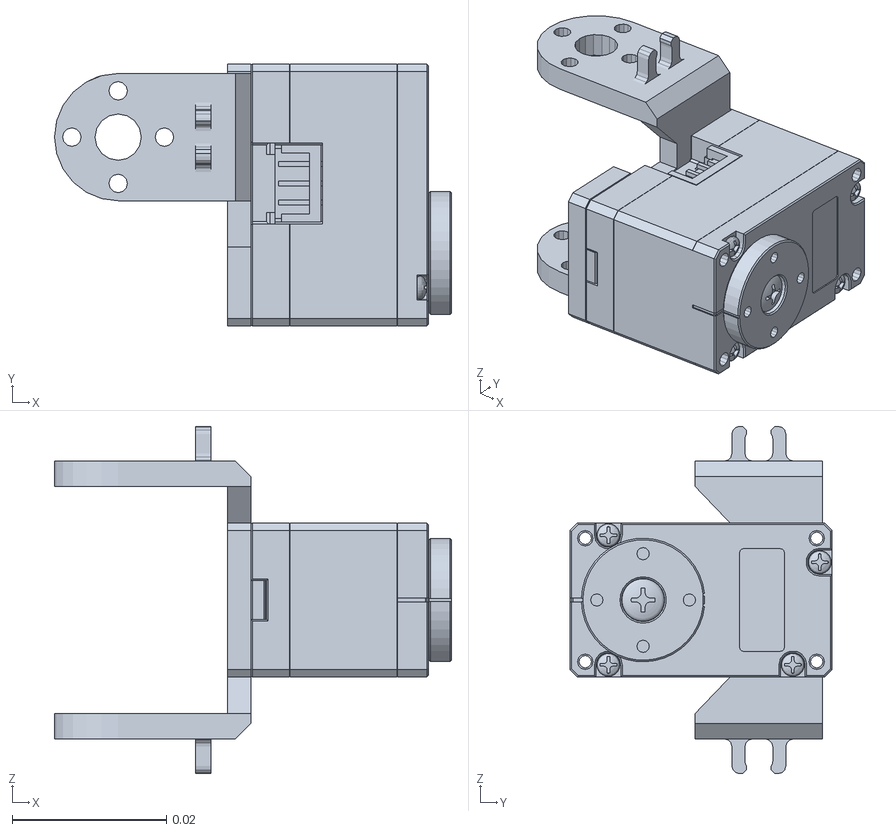
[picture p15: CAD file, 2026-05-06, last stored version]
meshes/arm_wrist_pitch.STL
0.0515 x 0.034 x 0.045

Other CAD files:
meshes/r_hip_pitch.STL
meshes/r_hip_roll.STL
meshes/l_hip_yaw.STL
meshes/l_foot_roll.STL
meshes/l_knee_pitch.STL
meshes/l_hip_roll.STL
meshes/arm_link_1.STL
meshes/arm_link_2.STL
meshes/arm_shoulder_pitch.STL
meshes/arm_wheel_pitch_.STL
meshes/elbow_wheel.STL
meshes/end_effector.STL
meshes/l_ankle_joint.STL
meshes/l_foot_link.STL
meshes/l_hip_pitch_joint.STL
meshes/l_hip_roll_joint.STL
meshes/l_knee_joint.STL
meshes/l_knee_wheel.STL
meshes/r_ankle_joint.STL
meshes/r_ankle_pitch.STL
meshes/r_foot_link.STL
meshes/r_hip_pitch_link.STL
meshes/r_hip_roll_joint.STL
meshes/r_knee_joint.STL
meshes/r_knee_wheel.STL
meshes/waist_yaw_link.STL
solidworks_export/meshes/arm_link_1.STL
solidworks_export/meshes/arm_link_2.STL
solidworks_export/meshes/arm_shoulder_pitch.STL
solidworks_export/meshes/arm_wheel_pitch_.STL
solidworks_export/meshes/elbow_wheel.STL
solidworks_export/meshes/end_effector.STL
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

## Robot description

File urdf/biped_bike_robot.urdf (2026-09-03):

<?xml version="1.0" encoding="utf-8"?>
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
<robot name="biped_bike_robot_print_ver6">
  <link name="base_link">
    <inertial>
      <origin xyz="-0.066549 -0.076779 0.018299" rpy="0 0 0" />
      <mass value="0.62617" />
      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
    </inertial>
    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
  </link>
  <link name="l_hip_yaw">
    <inertial>
      <origin xyz="-0.0138 6.382E-10 -0.013274" rpy="0 0 0" />
      <mass value="0.02669" />
      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
    </inertial>
    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
  </link>
  <joint name="l_hip_yaw_jnt" type="revolute">
    <origin xyz="-0.01525 -0.01425 0.0026" rpy="0 0 0" />
    <parent link="base_link" />
    <child link="l_hip_yaw" />
    <axis xyz="0 0 -1" />
    <limit lower="-3.14159" upper="3.14159" effort="1.5" velocity="6.38" />
    <dynamics damping="0.1" friction="0.1" />
  </joint>
  <link name="l_hip_roll">
    <inertial>
      <origin xyz="-0.012167 -0.00018746 0.046558" rpy="0 0 0" />
      <mass value="0.11819" />
      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
    </inertial>
    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
  </link>
  <joint name="l_hip_roll_jnt" type="revolute">
    <origin xyz="-0.0594 0 -0.0376" rpy="0 -1.5708 3.14159" />
    <parent link="l_hip_yaw" />
    <child link="l_hip_roll" />
    <axis xyz="0 0 -1" />
    <limit lower="-3.14159" upper="3.14159" effort="1.5" velocity="6.38" />
    <dynamics damping="0.1" friction="0.1" />
  </joint>
  <link name="l_hip_pitch">
    <inertial>
      <origin xyz="-1.1102E-16 0.0295 -0.0209" rpy="0 0 0" />
      <mass value="0.014036" />
      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
    </inertial>
    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
  </link>
  <joint name="l_hip_pitch_jnt" type="revolute">
    <origin xyz="-0.024 -0.0209 0.0614" rpy="1.5708 -1.5708 0" />
    <parent link="l_hip_roll" />
    <child link="l_hip_pitch" />
    <axis xyz="0 0 1" />
    <limit lower="-3.14159" upper="3.14159" effort="1.5" velocity="6.38" />
    <dynamics damping="0.1" friction="0.1" />
  </joint>
  <link name="l_knee_pitch">
    <inertial>
      <origin xyz="0.016601 0.023502 -0.020593" rpy="0 0 0" />
      <mass value="0.14629" />
      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
    </inertial>
    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
  </link>
  <joint name="l_knee_pitch_jnt" type="revolute">
    <origin xyz="0 0.059 0" rpy="0 0 0" />
    <parent link="l_hip_pitch" />
    <child link="l_knee_pitch" />
    <axis xyz="0 0 -1" />
    <limit lower="-3.14159" upper="3.14159" effort="3.0" velocity="8.063" />
    <dynamics damping="0.1" friction="0.1" />
  </joint>
  <link name="l_ankle_pitch">
    <inertial>
      <origin xyz="-0.01485 0.011601 -0.020714" rpy="0 0 0" />
      <mass value="0.11819" />
      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
    </inertial>
    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
  </link>
  <joint name="l_ankle_pitch_jnt" type="revolute">
    <origin xyz="-0.003 0.1125 0" rpy="0 0 0" />
    <parent link="l_knee_pitch" />
    <child link="l_ankle_pitch" />
    <axis xyz="0 0 -1" />
    <limit lower="-3.14159" upper="3.14159" effort="1.5" velocity="6.38" />
    <dynamics damping="0.1" friction="0.1" />
  </joint>
  <link name="l_foot_roll">
    <inertial>
      <origin xyz="-0.050982 2.7756E-16 0.058939" rpy="0 0 0" />
      <mass value="0.074723" />
      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
    </inertial>
    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
  </link>
  <joint name="l_foot_roll_jnt" type="revolute">
    <origin xyz="-0.0614 0 -0.0209" rpy="-1.5708 0 -1.5708" />
    <parent link="l_ankle_pitch" />
    <child link="l_foot_roll" />
    <axis xyz="0 0 -1" />
    <limit lower="-3.14159" upper="3.14159" effort="3.0" velocity="8.063" />
    <dynamics damping="0.1" friction="0.1" />
  </joint>
  <link name="l_knee_pitch_wheel">
    <inertial>
      <origin xyz="3.3487E-13 -6.9322E-13 0.017202" rpy="0 0 0" />
      <mass value="0.016569" />
      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
    </inertial>
    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
  </link>
  <joint name="l_knee_pitch_wheel_jnt" type="continuous">
    <origin xyz="0.041 0 0" rpy="0 0 0" />
    <parent link="l_knee_pitch" />
    <child link="l_knee_pitch_wheel" />
    <axis xyz="0 0 -1" />
    <limit effort="1.5" velocity="6.38" />
    <dynamics damping="0.1" friction="0.1" />
  </joint>
  <link name="r_hip_yaw">
    <inertial>
      <origin xyz="-0.0138 6.382E-10 -0.013274" rpy="0 0 0" />
      <mass value="0.02669" />
      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
    </inertial>
    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
  </link>
  <joint name="r_hip_yaw_jnt" type="revolute">
    <origin xyz="-0.01525 -0.13925 0.0026" rpy="0 0 0" />
    <parent link="base_link" />
    <child link="r_hip_yaw" />
    <axis xyz="0 0 -1" />
    <limit lower="-3.14159" upper="3.14159" effort="1.5" velocity="6.38" />
    <dynamics damping="0.1" friction="0.1" />
  </joint>
  <link name="r_hip_roll">
    <inertial>
      <origin xyz="-0.012165 -0.00018769 0.046558" rpy="0 0 0" />
      <mass value="0.11819" />
      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
    </inertial>
    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
  </link>
  <joint name="r_hip_roll_jnt" type="revolute">
    <origin xyz="-0.0594 0 -0.0376" rpy="0 -1.5708 3.14159" />
    <parent link="r_hip_yaw" />
    <child link="r_hip_roll" />
    <axis xyz="0 0 -1" />
    <limit lower="-3.14159" upper="3.14159" effort="1.5" velocity="6.38" />
    <dynamics damping="0.1" friction="0.1" />
  </joint>
  <link name="r_hip_pitch">
    <inertial>
      <origin xyz="-2.7756E-17 0.0295 -0.0209" rpy="0 0 0" />
      <mass value="0.014036" />
      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
    </inertial>
    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
  </link>
  <joint name="r_hip_pitch_jnt" type="revolute">
    <origin xyz="-0.024 -0.0209 0.0614" rpy="1.5708 -1.5708 0" />
    <parent link="r_hip_roll" />
    <child link="r_hip_pitch" />
    <axis xyz="0 0 -1" />
    <limit lower="-3.14159" upper="3.14159" effort="1.5" velocity="6.38" />
    <dynamics damping="0.1" friction="0.1" />
  </joint>
  <link name="r_knee_pitch">
    <inertial>
      <origin xyz="0.016601 0.02357 -0.020593" rpy="0 0 0" />
      <mass value="0.14629" />
      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
    </inertial>
    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
  </link>
  <joint name="r_knee_pitch_jnt" type="revolute">
    <origin xyz="0 0.059 0" rpy="0 0 0" />
    <parent link="r_hip_pitch" />
    <child link="r_knee_pitch" />
    <axis xyz="0 0 -1" />
    <limit lower="-3.14159" upper="3.14159" effort="3.0" velocity="8.063" />
    <dynamics damping="0.1" friction="0.1" />
  </joint>
  <link name="r_ankle_pitch">
    <inertial>
      <origin xyz="-0.01285 0.011851 -0.020714" rpy="0 0 0" />
      <mass value="0.11819" />
      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
    </inertial>
    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
  </link>
  <joint name="r_ankle_pitch_jnt" type="revolute">
    <origin xyz="-0.005 0.1125 0" rpy="0 0 0" />
    <parent link="r_knee_pitch" />
    <child link="r_ankle_pitch" />
    <axis xyz="0 0 -1" />
    <limit lower="-3.14159" upper="3.14159" effort="1.5" velocity="6.38" />
    <dynamics damping="0.1" friction="0.1" />
  </joint>
  <link name="r_foot_roll">
    <inertial>
      <origin xyz="-0.050982 2.9143E-16 0.058939" rpy="0 0 0" />
      <mass value="0.074723" />
      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
    </inertial>
    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
  </link>
  <joint name="r_foot_roll_jnt" type="revolute">
    <origin xyz="-0.0594 0.00025 -0.0209" rpy="-1.5708 0 -1.5708" />
    <parent link="r_ankle_pitch" />
    <child link="r_foot_roll" />
    <axis xyz="0 0 -1" />
    <limit lower="-3.14159" upper="3.14159" effort="3.0" velocity="8.063" />
    <dynamics damping="0.1" friction="0.1" />
  </joint>
  <link name="r_knee_pitch_wheel">
    <inertial>
      <origin xyz="3.6692E-13 6.7643E-13 -0.059002" rpy="0 0 0" />
      <mass value="0.016569" />
      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
    </inertial>
    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
  </link>
  <joint name="r_knee_pitch_wheel_jnt" type="continuous">
    <origin xyz="0.041 0 0" rpy="0 0 0" />
    <parent link="r_knee_pitch" />
    <child link="r_knee_pitch_wheel" />
    <axis xyz="0 0 1" />
    <limit effort="1.5" velocity="6.38" />
    <dynamics damping="0.1" friction="0.1" />
  </joint>
  <link name="arm_base_yaw">
    <inertial>
      <origin xyz="-0.00017614 0.000428 0.026853" rpy="0 0 0" />
      <mass value="0.052551" />
      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
    </inertial>
    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
  </link>
  <joint name="arm_base_yaw_jnt" type="revolute">
    <origin xyz="-0.01505 -0.07695 0.0444" rpy="0 0 0" />
    <parent link="base_link" />
    <child link="arm_base_yaw" />
    <axis xyz="0 0 -1" />
    <limit lower="-3.14159" upper="3.14159" effort="1.5" velocity="6.38" />
    <dynamics damping="0.1" friction="0.1" />
  </joint>
  <link name="arm_shoulder_pitch">
    <inertial>
      <origin xyz="0.01169 -0.10577 -0.02048" rpy="0 0 0" />
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

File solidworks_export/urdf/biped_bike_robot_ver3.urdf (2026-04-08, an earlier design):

<?xml version="1.0" encoding="utf-8"?>
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
<robot name="biped_bike_robot_ver3">
  <link name="base_link">
    <inertial>
      <origin xyz="-0.027467 -0.076798 0.018551" rpy="0 0 0" />
      <mass value="0.20217" />
      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
    </inertial>
    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
  </link>
  <link name="l_hip_yaw">
    <inertial>
      <origin xyz="-0.014647 6.7734E-10 -0.01155" rpy="0 0 0" />
      <mass value="0.027291" />
      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
    </inertial>
    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
  </link>
  <joint name="l_hip_yaw" type="revolute">
    <origin xyz="-0.01525 -0.01425 0.0026" rpy="0 0 0" />
    <parent link="base_link" />
    <child link="l_hip_yaw" />
    <axis xyz="0 0 -1" />
    <limit lower="0" upper="0" effort="0" velocity="0" />
  </joint>
  <link name="l_hip_roll">
    <inertial>
      <origin xyz="-0.01217 -0.00018948 0.046417" rpy="0 0 0" />
      <mass value="0.11708" />
      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
    </inertial>
    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
  </link>
  <joint name="l_hip_roll" type="revolute">
    <origin xyz="-0.0614 0 -0.0356" rpy="0 -1.5708 0" />
    <parent link="l_hip_yaw" />
    <child link="l_hip_roll" />
    <axis xyz="0 0 -1" />
    <limit lower="0" upper="0" effort="0" velocity="0" />
  </joint>
  <link name="l_hip_pitch">
    <inertial>
      <origin xyz="-3.9552E-15 0.0295 -0.0209" rpy="0 0 0" />
      <mass value="0.016365" />
      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
    </inertial>
    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
  </link>
  <joint name="l_hip_pitch" type="revolute">
    <origin xyz="-0.024 -0.0209 0.0614" rpy="1.5708 -1.5708 0" />
    <parent link="l_hip_roll" />
    <child link="l_hip_pitch" />
    <axis xyz="0 0 1" />
    <limit lower="0" upper="0" effort="0" velocity="0" />
  </joint>
  <link name="l_knee_pitch">
    <inertial>
      <origin xyz="0.020267 0.018916 -0.020589" rpy="0 0 0" />
      <mass value="0.14474" />
      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
    </inertial>
    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
  </link>
  <joint name="l_knee_pitch" type="revolute">
    <origin xyz="0 0.059 0" rpy="0 0 0" />
    <parent link="l_hip_pitch" />
    <child link="l_knee_pitch" />
    <axis xyz="0 0 -1" />
    <limit lower="0" upper="0" effort="0" velocity="0" />
  </joint>
  <link name="l_ankle_pitch">
    <inertial>
      <origin xyz="-0.014991 0.011589 -0.020713" rpy="0 0 0" />
      <mass value="0.11708" />
      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
    </inertial>
    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
  </link>
  <joint name="l_ankle_pitch" type="revolute">
    <origin xyz="0 0.08775 0" rpy="0 0 0" />
    <parent link="l_knee_pitch" />
    <child link="l_ankle_pitch" />
    <axis xyz="0 0 -1" />
    <limit lower="0" upper="0" effort="0" velocity="0" />
  </joint>
  <link name="l_foot_roll">
    <inertial>
      <origin xyz="-0.051554 -2.0817E-16 0.061016" rpy="0 0 0" />
      <mass value="0.073461" />
      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
    </inertial>
    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
  </link>
  <joint name="l_foot_roll" type="revolute">
    <origin xyz="-0.0614 0 -0.0209" rpy="-1.5708 0 -1.5708" />
    <parent link="l_ankle_pitch" />
    <child link="l_foot_roll" />
    <axis xyz="0 0 -1" />
    <limit lower="0" upper="0" effort="0" velocity="0" />
  </joint>
  <link name="l_knee_pitch_wheel">
    <inertial>
      <origin xyz="9.0919E-13 -3.7224E-13 0.0055204" rpy="0 0 0" />
      <mass value="0.012433" />
      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
    </inertial>
    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
  </link>
  <joint name="l_knee_pitch_wheel" type="continuous">
    <origin xyz="0.047 0.024 0" rpy="0 0 0" />
    <parent link="l_knee_pitch" />
    <child link="l_knee_pitch_wheel" />
    <axis xyz="0 0 -1" />
  </joint>
  <link name="r_hip_yaw">
    <inertial>
      <origin xyz="-0.014647 6.7734E-10 -0.01155" rpy="0 0 0" />
      <mass value="0.027291" />
      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
    </inertial>
    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
  </link>
  <joint name="r_hip_yaw" type="revolute">
    <origin xyz="-0.01525 -0.13925 0.0026" rpy="0 0 0" />
    <parent link="base_link" />
    <child link="r_hip_yaw" />
    <axis xyz="0 0 -1" />
    <limit lower="0" upper="0" effort="0" velocity="0" />
  </joint>
  <link name="r_hip_roll">
    <inertial>
      <origin xyz="-0.01217 -0.00018948 0.046417" rpy="0 0 0" />
      <mass value="0.11708" />
      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
    </inertial>
    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
  </link>
  <joint name="r_hip_roll" type="revolute">
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

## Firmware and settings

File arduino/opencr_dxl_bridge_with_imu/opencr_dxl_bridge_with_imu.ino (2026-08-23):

#include <Arduino.h>
#include <IMU.h>

// OpenCR USB-to-Dynamixel TTL bridge with a virtual OpenCR IMU sensor.
//
// Normal packets are forwarded:
//   PC USB Serial <-> OpenCR Serial3 <-> Dynamixel TTL bus
//
// Read/Ping packets addressed to VIRTUAL_IMU_ID are answered by OpenCR itself.
// This lets the PC read the built-in IMU through the same Dynamixel SDK port
// while the robot is moving.

#define USB_PORT Serial
#define DXL_PORT Serial3

#define DEFAULT_DXL_BAUD 1000000
#define BUFFER_LENGTH 1024
#define USB_PACKET_BUFFER_LENGTH 512

#define VIRTUAL_IMU_ID 200
#define VIRTUAL_TABLE_SIZE 180
#define ADDR_IMU_BLOCK 100
#define LEN_IMU_BLOCK 68

#define INST_PING 0x01
#define INST_READ 0x02
#define INST_STATUS 0x55

#define ERR_NONE 0x00
#define ERR_INSTRUCTION 0x02
#define ERR_DATA_RANGE 0x04

#define LED_USB_TO_DXL BDPIN_LED_USER_1
#define LED_DXL_TO_USB BDPIN_LED_USER_2

static uint8_t bridge_buffer[BUFFER_LENGTH];
static uint8_t usb_packet_buffer[USB_PACKET_BUFFER_LENGTH];
static size_t usb_packet_length = 0;
static uint8_t virtual_table[VIRTUAL_TABLE_SIZE];
static uint32_t current_dxl_baud = DEFAULT_DXL_BAUD;

static uint8_t usb_to_dxl_led_count = 0;
static uint8_t dxl_to_usb_led_count = 0;
static uint32_t last_usb_to_dxl_led_ms = 0;
static uint32_t last_dxl_to_usb_led_ms = 0;

static cIMU imu;

static void setDxlPower(bool enabled)
{
  digitalWrite(BDPIN_DXL_PWR_EN, enabled ? HIGH : LOW);
}

static void setDxlTx(bool enabled)
{
  drv_dxl_tx_enable(enabled ? 1 : 0);
}

static uint16_t updateCrc(uint16_t crc_accum, const uint8_t *data_blk_ptr, uint16_t data_blk_size)
{
  for (uint16_t j = 0; j < data_blk_size; ++j) {
    crc_accum ^= static_cast<uint16_t>(data_blk_ptr[j]) << 8;
    for (uint8_t i = 0; i < 8; ++i) {
      if (crc_accum & 0x8000) {
        crc_accum = (crc_accum << 1) ^ 0x8005;
      } else {
        crc_accum <<= 1;
      }
    }
  }
  return crc_accum;
}

static bool hasValidHeader(const uint8_t *packet)
{
  return packet[0] == 0xFF && packet[1] == 0xFF && packet[2] == 0xFD && packet[3] == 0x00;
}

static bool hasValidCrc(const uint8_t *packet, size_t packet_length)
{
  if (packet_length < 10) {
    return false;
  }

  uint16_t expected = updateCrc(0, packet, packet_length - 2);
  uint16_t actual = packet[packet_length - 2] | (static_cast<uint16_t>(packet[packet_length - 1]) << 8);
  return expected == actual;
}

static void putU16(uint16_t address, uint16_t value)
{
  if (address + 1 >= VIRTUAL_TABLE_SIZE) {
    return;
  }
  virtual_table[address] = value & 0xFF;
  virtual_table[address + 1] = (value >> 8) & 0xFF;
}

static void putU32(uint16_t address, uint32_t value)
{
  if (address + 3 >= VIRTUAL_TABLE_SIZE) {
    return;
  }
  virtual_table[address] = value & 0xFF;
  virtual_table[address + 1] = (value >> 8) & 0xFF;
  virtual_table[address + 2] = (value >> 16) & 0xFF;
  virtual_table[address + 3] = (value >> 24) & 0xFF;
}

static void putI16(uint16_t address, int16_t value)
{
  putU16(address, static_cast<uint16_t>(value));
}

static void putFloat(uint16_t address, float value)
{
  if (address + 3 >= VIRTUAL_TABLE_SIZE) {
    return;
  }
  memcpy(&virtual_table[address], &value, sizeof(float));
}

static void updateVirtualTable()
{
  memset(virtual_table, 0, sizeof(virtual_table));

  putU16(0, 2000);
  virtual_table[6] = 1;
  virtual_table[7] = VIRTUAL_IMU_ID;
  virtual_table[8] = 3;
  virtual_table[13] = 2;
  virtual_table[68] = 2;

  putU32(ADDR_IMU_BLOCK + 0, millis());
  putFloat(ADDR_IMU_BLOCK + 4, imu.quat[0]);
  putFloat(ADDR_IMU_BLOCK + 8, imu.quat[1]);
  putFloat(ADDR_IMU_BLOCK + 12, imu.quat[2]);
  putFloat(ADDR_IMU_BLOCK + 16, imu.quat[3]);

  putFloat(ADDR_IMU_BLOCK + 20, imu.rpy[0]);
  putFloat(ADDR_IMU_BLOCK + 24, imu.rpy[1]);
  putFloat(ADDR_IMU_BLOCK + 28, imu.rpy[2]);

  putFloat(ADDR_IMU_BLOCK + 32, imu.gx);
  putFloat(ADDR_IMU_BLOCK + 36, imu.gy);
  putFloat(ADDR_IMU_BLOCK + 40, imu.gz);

  putFloat(ADDR_IMU_BLOCK + 44, imu.ax);
  putFloat(ADDR_IMU_BLOCK + 48, imu.ay);
  putFloat(ADDR_IMU_BLOCK + 52, imu.az);

  putI16(ADDR_IMU_BLOCK + 56, imu.gyroData[0]);
  putI16(ADDR_IMU_BLOCK + 58, imu.gyroData[1]);
  putI16(ADDR_IMU_BLOCK + 60, imu.gyroData[2]);
  putI16(ADDR_IMU_BLOCK + 62, imu.accData[0]);
  putI16(ADDR_IMU_BLOCK + 64, imu.accData[1]);
  putI16(ADDR_IMU_BLOCK + 66, imu.accData[2]);
}

static void sendStatusPacket(uint8_t error, const uint8_t *params, uint16_t param_length)
{
  uint16_t status_length = param_length + 4;
  uint16_t total_length = param_length + 11;

  if (total_length > BUFFER_LENGTH) {
    return;
  }

  bridge_buffer[0] = 0xFF;
  bridge_buffer[1] = 0xFF;
  bridge_buffer[2] = 0xFD;
  bridge_buffer[3] = 0x00;
  bridge_buffer[4] = VIRTUAL_IMU_ID;
  bridge_buffer[5] = status_length & 0xFF;
  bridge_buffer[6] = (status_length >> 8) & 0xFF;
  bridge_buffer[7] = INST_STATUS;
  bridge_buffer[8] = error;

  if (param_length > 0 && params != nullptr) {
    memcpy(&bridge_buffer[9], params, param_length);
  }

  uint16_t crc = updateCrc(0, bridge_buffer, total_length - 2);
  bridge_buffer[total_length - 2] = crc & 0xFF;
  bridge_buffer[total_length - 1] = (crc >> 8) & 0xFF;

  USB_PORT.write(bridge_buffer, total_length);
  USB_PORT.flush();
  dxl_to_usb_led_count = 4;
}

static void handleVirtualPacket(const uint8_t *packet, size_t packet_length)
{
  if (!hasValidCrc(packet, packet_length)) {
    return;
  }

  uint8_t instruction = packet[7];

  if (instruction == INST_PING) {
    uint8_t params[3] = {
      static_cast<uint8_t>(virtual_table[0]),
      static_cast<uint8_t>(virtual_table[1]),
      static_cast<uint8_t>(virtual_table[6]),
    };
    sendStatusPacket(ERR_NONE, params, sizeof(params));
    return;
  }

  if (instruction != INST_READ) {
    sendStatusPacket(ERR_INSTRUCTION, nullptr, 0);
    return;
  }

  uint16_t address = packet[8] | (static_cast<uint16_t>(packet[9]) << 8);
  uint16_t read_length = packet[10] | (static_cast<uint16_t>(packet[11]) << 8);
  if (address + read_length > VIRTUAL_TABLE_SIZE || read_length > 200) {
    sendStatusPacket(ERR_DATA_RANGE, nullptr, 0);
    return;
  }

  updateVirtualTable();
  sendStatusPacket(ERR_NONE, &virtual_table[address], read_length);
}

static void forwardPacketToDxl(const uint8_t *packet, size_t packet_length)
{
  setDxlTx(true);
  DXL_PORT.write(packet, packet_length);
  DXL_PORT.flush();
  setDxlTx(false);
  usb_to_dxl_led_count = 4;
}

static void processUsbPacketBuffer()
{
  while (usb_packet_length >= 7) {
    if (!hasValidHeader(usb_packet_buffer)) {
      memmove(usb_packet_buffer, usb_packet_buffer + 1, usb_packet_length - 1);
      --usb_packet_length;
      continue;
    }

    uint16_t packet_length_field = usb_packet_buffer[5] | (static_cast<uint16_t>(usb_packet_buffer[6]) << 8);
    size_t full_packet_length = static_cast<size_t>(packet_length_field) + 7;
    if (full_packet_length > USB_PACKET_BUFFER_LENGTH) {
      usb_packet_length = 0;
      return;
    }
    if (usb_packet_length < full_packet_length) {
      return;
    }

    if (usb_packet_buffer[4] == VIRTUAL_IMU_ID) {
      handleVirtualPacket(usb_packet_buffer, full_packet_length);
    } else {
      forwardPacketToDxl(usb_packet_buffer, full_packet_length);
    }

    size_t remaining = usb_packet_length - full_packet_length;
    if (remaining > 0) {
      memmove(usb_packet_buffer, usb_packet_buffer + full_packet_length, remaining);
    }
    usb_packet_length = remaining;
  }
}

static void updateDxlBridge()
{
  while (USB_PORT.available() > 0) {
    int value = USB_PORT.read();
    if (value < 0) {
      break;
    }
    if (usb_packet_length < USB_PACKET_BUFFER_LENGTH) {
      usb_packet_buffer[usb_packet_length++] = static_cast<uint8_t>(value);
    } else {
      usb_packet_length = 0;
    }
  }
  processUsbPacketBuffer();

  int length = DXL_PORT.available();
  if (length > BUFFER_LENGTH) {
    length = BUFFER_LENGTH;
  }
  if (length > 0) {
    for (int i = 0; i < length; ++i) {
      int value = DXL_PORT.read();
      if (value < 0) {
        length = i;
        break;
      }
      bridge_buffer[i] = static_cast<uint8_t>(value);
    }

    if (length > 0) {
      USB_PORT.write(bridge_buffer, length);
      USB_PORT.flush();
      dxl_to_usb_led_count = 4;
    }
  }
}

static void syncDxlBaudWithUsb()
{
  uint32_t usb_baud = USB_PORT.getBaudRate();
  if (usb_baud == 0) {
    usb_baud = DEFAULT_DXL_BAUD;
  }

  if (usb_baud != current_dxl_baud) {
    DXL_PORT.begin(usb_baud);
    current_dxl_baud = usb_baud;
  }
}

static void updateLed()
{
  uint32_t now = millis();

  if (now - last_usb_to_dxl_led_ms > 40) {
    last_usb_to_dxl_led_ms = now;
    if (usb_to_dxl_led_count > 0) {
      digitalWrite(LED_USB_TO_DXL, !digitalRead(LED_USB_TO_DXL));
      --usb_to_dxl_led_count;
    } else {
      digitalWrite(LED_USB_TO_DXL, HIGH);
    }
  }

  if (now - last_dxl_to_usb_led_ms > 40) {
    last_dxl_to_usb_led_ms = now;
    if (dxl_to_usb_led_count > 0) {
      digitalWrite(LED_DXL_TO_USB, !digitalRead(LED_DXL_TO_USB));
      --dxl_to_usb_led_count;
    } else {
      digitalWrite(LED_DXL_TO_USB, HIGH);
    }
  }
}

void setup()
{
  pinMode(BDPIN_DXL_PWR_EN, OUTPUT);
  pinMode(LED_USB_TO_DXL, OUTPUT);
  pinMode(LED_DXL_TO_USB, OUTPUT);

  digitalWrite(LED_USB_TO_DXL, HIGH);
  digitalWrite(LED_DXL_TO_USB, HIGH);

  USB_PORT.begin(DEFAULT_DXL_BAUD);
  DXL_PORT.begin(DEFAULT_DXL_BAUD);
  current_dxl_baud = DEFAULT_DXL_BAUD;

  setDxlTx(false);
  setDxlPower(true);

  imu.begin();
  updateVirtualTable();
}

void loop()
{
  imu.update();
  syncDxlBaudWithUsb();
  updateDxlBridge();
  updateLed();
}

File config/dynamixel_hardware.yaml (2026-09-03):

bus:
  device: /dev/opencr
  baudrate: 1000000
  protocol_version: 2.0
  transport: ttl
  model: mixed

defaults:
  model: XL430-W250
  effort_feedback: load
  stall_torque_nm: 1.4
  current_unit_a: 0.00269
  stall_current_a: 1.0
  position_center_tick: 2048
  position_mode: 3
  velocity_mode: 1
  profile_velocity: null
  pwm_limit: 885
  profile_acceleration: null
  position_p_gain: null
  position_i_gain: null
  position_d_gain: null
  torque_enable_on_start: false
  direction: 1
  direction_checked: true

control_table:
  operating_mode: 11
  pwm_limit: 36
  torque_enable: 64
  led: 65
  position_d_gain: 80
  position_i_gain: 82
  position_p_gain: 84
  goal_velocity: 104
  profile_acceleration: 108
  profile_velocity: 112
  goal_position: 116
  present_pwm: 124
  present_load: 126
  present_velocity: 128
  present_position: 132
  present_input_voltage: 144
  present_temperature: 146

conversion:
  ticks_per_rev: 4096
  center_tick: 2048
  rad_per_tick: 0.0015339807878856412
  tick_per_rad: 651.8986469044033
  velocity_unit_rpm: 0.229
  velocity_unit_rad_per_sec: 0.023980823922402087
  velocity_raw_per_rad_per_sec: 41.7006433385832

joints:
  - id: 1
    joint_name: l_hip_yaw_jnt
    joint_type: revolute
    control_mode: position
    operating_mode: 3
    center_tick: 2048
    direction: -1
    direction_checked: true
    active: true
    notes: URDF zero is motor tick 2048

  - id: 2
    joint_name: l_hip_roll_jnt
    joint_type: revolute
    control_mode: position
    operating_mode: 3
    center_tick: 2048
    direction: 1
    position_p_gain: 1000
    direction_checked: true
    active: true

  - id: 3
    joint_name: l_hip_pitch_jnt
    joint_type: revolute
    control_mode: position
    operating_mode: 3
    center_tick: 2048
    direction: 1
    position_p_gain: 800
    position_i_gain: 0
    position_d_gain: 2400
    direction_checked: true
    active: true

  - id: 4
    joint_name: l_knee_pitch_jnt
    model: XM430-W210-R
    effort_feedback: current
    stall_torque_nm: 3.0
    stall_current_a: 2.3
    no_load_speed_rpm: 77.0
    joint_type: revolute
    control_mode: position
    operating_mode: 3
    center_tick: 2048
    direction: -1
    direction_checked: true
    active: true

  - id: 5
    joint_name: l_ankle_pitch_jnt
    joint_type: revolute
    control_mode: position
    operating_mode: 3
    center_tick: 2048
    direction: -1
    position_p_gain: 800
    position_i_gain: 0
    position_d_gain: 2400
    direction_checked: true
    active: true

  - id: 6
    joint_name: l_foot_roll_jnt
    model: XM430-W210-R
    effort_feedback: current
    stall_torque_nm: 3.0
    stall_current_a: 2.3
    no_load_speed_rpm: 77.0
    joint_type: revolute
    control_mode: position
    operating_mode: 3
    center_tick: 2048
    direction: -1
    position_p_gain: 1000
    direction_checked: true
    active: true

  - id: 7
    joint_name: l_knee_pitch_wheel_jnt
    joint_type: continuous
    control_mode: velocity
    operating_mode: 1
    direction: 1
    direction_checked: true
    active: true
    notes: Left drive wheel

  - id: 8
    joint_name: r_hip_yaw_jnt
    joint_type: revolute
    control_mode: position
    operating_mode: 3
    center_tick: 2048
    direction: -1
    direction_checked: true
    active: true

  - id: 9
    joint_name: r_hip_roll_jnt
    joint_type: revolute
    control_mode: position
    operating_mode: 3
    center_tick: 2048
    direction: 1
    position_p_gain: 1000
    direction_checked: true
    active: true

  - id: 10
    joint_name: r_hip_pitch_jnt
    joint_type: revolute
    control_mode: position
    operating_mode: 3
    center_tick: 2048
    direction: 1
    position_p_gain: 800
    position_i_gain: 0
    position_d_gain: 2400
    direction_checked: true
    active: true

  - id: 11
    joint_name: r_knee_pitch_jnt
    model: XM430-W210-R
    effort_feedback: current
    stall_torque_nm: 3.0
    stall_current_a: 2.3
    no_load_speed_rpm: 77.0
    joint_type: revolute
    control_mode: position
    operating_mode: 3
    center_tick: 2048
    direction: 1
    direction_checked: true
    active: true

  - id: 12
    joint_name: r_ankle_pitch_jnt
    joint_type: revolute
    control_mode: position
    operating_mode: 3
    center_tick: 2048
    direction: 1
    position_p_gain: 800
    position_i_gain: 0
    position_d_gain: 2400
    direction_checked: true
    active: true

  - id: 13
    joint_name: r_foot_roll_jnt
    model: XM430-W210-R
    effort_feedback: current
    stall_torque_nm: 3.0
    stall_current_a: 2.3
    no_load_speed_rpm: 77.0
    joint_type: revolute
    control_mode: position
    operating_mode: 3
    center_tick: 2048
    direction: -1
    position_p_gain: 1000
    direction_checked: true
    active: true

  - id: 14
    joint_name: r_knee_pitch_wheel_jnt
    joint_type: continuous
    control_mode: velocity
    operating_mode: 1
    direction: 1
    direction_checked: true
    active: true
    notes: Right drive wheel
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

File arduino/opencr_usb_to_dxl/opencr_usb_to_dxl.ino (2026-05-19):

#include <Arduino.h>

// OpenCR USB-to-Dynamixel TTL passthrough.
//
// This sketch makes the OpenCR behave like a simple U2D2-style adapter:
//   PC USB Serial <-> OpenCR Serial3 <-> Dynamixel TTL bus
//
// Do not print debug text to Serial. The PC-side Dynamixel SDK expects raw
// Dynamixel packets only, and any extra bytes on USB will corrupt packets.

#define USB_PORT Serial
#define DXL_PORT Serial3

#define DEFAULT_DXL_BAUD 1000000
#define BUFFER_LENGTH 1024

#define LED_USB_TO_DXL BDPIN_LED_USER_1
#define LED_DXL_TO_USB BDPIN_LED_USER_2

static uint8_t buffer[BUFFER_LENGTH];
static uint32_t current_dxl_baud = DEFAULT_DXL_BAUD;

static uint8_t usb_to_dxl_led_count = 0;
static uint8_t dxl_to_usb_led_count = 0;
static uint32_t last_usb_to_dxl_led_ms = 0;
static uint32_t last_dxl_to_usb_led_ms = 0;

static void setDxlPower(bool enabled)
{
  digitalWrite(BDPIN_DXL_PWR_EN, enabled ? HIGH : LOW);
}

static void setDxlTx(bool enabled)
{
  drv_dxl_tx_enable(enabled ? 1 : 0);
}

static void syncDxlBaudWithUsb()
{
  uint32_t usb_baud = USB_PORT.getBaudRate();

  if (usb_baud == 0) {
    usb_baud = DEFAULT_DXL_BAUD;
  }

  if (usb_baud != current_dxl_baud) {
    DXL_PORT.begin(usb_baud);
    current_dxl_baud = usb_baud;
  }
}

static int readAvailable(HardwareSerial &port, uint8_t *dst, int max_len)
{
  int length = port.available();

  if (length > max_len) {
    length = max_len;
  }

  for (int i = 0; i < length; ++i) {
    int value = port.read();
    if (value < 0) {
      return i;
    }
    dst[i] = static_cast<uint8_t>(value);
  }

  return length;
}

static void updateDxlBridge()
{
  int length = USB_PORT.available();
  if (length > 0) {
    if (length > BUFFER_LENGTH) {
      length = BUFFER_LENGTH;
    }

    for (int i = 0; i < length; ++i) {
      int value = USB_PORT.read();
      if (value < 0) {
        length = i;
        break;
      }
      buffer[i] = static_cast<uint8_t>(value);
    }

    if (length > 0) {
      setDxlTx(true);
      DXL_PORT.write(buffer, length);
      DXL_PORT.flush();
      setDxlTx(false);

      usb_to_dxl_led_count = 4;
    }
  }

  length = readAvailable(DXL_PORT, buffer, BUFFER_LENGTH);
  if (length > 0) {
    USB_PORT.write(buffer, length);
    USB_PORT.flush();

    dxl_to_usb_led_count = 4;
  }
}

static void updateLed()
{
  uint32_t now = millis();

  if (now - last_usb_to_dxl_led_ms > 40) {
    last_usb_to_dxl_led_ms = now;
    if (usb_to_dxl_led_count > 0) {
      digitalWrite(LED_USB_TO_DXL, !digitalRead(LED_USB_TO_DXL));
      --usb_to_dxl_led_count;
    } else {
      digitalWrite(LED_USB_TO_DXL, HIGH);
    }
  }

  if (now - last_dxl_to_usb_led_ms > 40) {
    last_dxl_to_usb_led_ms = now;
    if (dxl_to_usb_led_count > 0) {
      digitalWrite(LED_DXL_TO_USB, !digitalRead(LED_DXL_TO_USB));
      --dxl_to_usb_led_count;
    } else {
      digitalWrite(LED_DXL_TO_USB, HIGH);
    }
  }
}

void setup()
{
  pinMode(BDPIN_DXL_PWR_EN, OUTPUT);
  pinMode(LED_USB_TO_DXL, OUTPUT);
  pinMode(LED_DXL_TO_USB, OUTPUT);

  digitalWrite(LED_USB_TO_DXL, HIGH);
  digitalWrite(LED_DXL_TO_USB, HIGH);

  USB_PORT.begin(DEFAULT_DXL_BAUD);
  DXL_PORT.begin(DEFAULT_DXL_BAUD);
  current_dxl_baud = DEFAULT_DXL_BAUD;

  setDxlTx(false);
  setDxlPower(true);
}

void loop()
{
  syncDxlBaudWithUsb();
  updateDxlBridge();
  updateLed();
}

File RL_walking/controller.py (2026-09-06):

"""Hardware mirror of the direct 12-joint position action."""

from __future__ import annotations

import numpy as np

try:
  from .contract import (
    ACTION_DIM,
    ACTION_SCALE_NEGATIVE,
    ACTION_SCALE_POSITIVE,
    READY_TARGET,
  )
except ImportError:
  from contract import (
    ACTION_DIM,
    ACTION_SCALE_NEGATIVE,
    ACTION_SCALE_POSITIVE,
    READY_TARGET,
  )


class FreeWalkingController:
  """Convert normalized policy output directly into 17 joint targets."""

  def __init__(self, action_filter_alpha: float = 1.0) -> None:
    if not 0.0 < action_filter_alpha <= 1.0:
      raise ValueError("action_filter_alpha must be in (0, 1]")
    self.raw_action = np.zeros(ACTION_DIM, np.float32)
    self.last_action = np.zeros(ACTION_DIM, np.float32)
    self._action_filter_alpha = np.float32(action_filter_alpha)
    self._negative_scale = np.asarray(ACTION_SCALE_NEGATIVE, np.float32)
    self._positive_scale = np.asarray(ACTION_SCALE_POSITIVE, np.float32)
    self._ready = np.asarray(READY_TARGET, np.float32)

  def reset(self) -> None:
    self.raw_action.fill(0.0)
    self.last_action.fill(0.0)

  def step(self, raw_action: np.ndarray) -> np.ndarray:
    self.raw_action[:] = np.clip(
      np.asarray(raw_action, np.float32).reshape(ACTION_DIM), -1.0, 1.0
    )
    if self._action_filter_alpha == 1.0:
      self.last_action[:] = self.raw_action
    else:
      self.last_action += self._action_filter_alpha * (
        self.raw_action - self.last_action
      )
    scale = np.where(
      self.last_action < 0.0, self._negative_scale, self._positive_scale
    )
    target = self._ready.copy()
    target[:ACTION_DIM] += self.last_action * scale
    return target

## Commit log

2026-03-11 feat: initial clean upload of robot package
    [arm_link_1.STL, arm_link_2.STL, base_link.STL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]
2026-04-08 feat: complete bipedal-to-3wheeled transformation sequence in simulation
    [arm_base_yaw.STL, arm_elbow_pitch.STL, arm_link_1.STL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]
2026-05-06 Update: Realistic URDF with battery/circuits, refined transformation logic, and stabilized OP3 walking engine
    [arm_base_yaw.STL, arm_elbow_pitch.STL, arm_shoulder_pitch.STL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]
2026-05-19 feat: add real robot hardware bridge
    [dynamixel_hardware.yaml]
2026-06-18 feat: 실물 동작 안정화 및 바이크 휠 키보드 제어 추가
    [biped_bike_robot.urdf, dynamixel_hardware.yaml]
2026-06-28 feat: update URDF v5 and add robot web interface
    [arm_base_yaw.STL, arm_elbow_pitch.STL, arm_shoulder_pitch.STL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]
2026-08-16 Update robot and configuration and transform logic
    [biped_bike_robot.urdf, biped_bike_robot_print_ver6.csv, biped_bike_robot_print_ver6.urdf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]
2026-08-23 Update robot docs and rename IK walker
    [biped_bike_robot_ver5.csv, biped_bike_robot_ver5.urdf, dynamixel_hardware.yaml]
2026-09-03 Update bike transform and robot control
    [biped_bike_robot.urdf, dynamixel_hardware.yaml]
2026-09-05 카메라 간섭을 고려한 변신 시퀀스 보정
2026-09-05 변신 후 hip_yaw 모으기 추가 (바퀴 안정성 확보)
2026-09-06 변신 안정성 확보
